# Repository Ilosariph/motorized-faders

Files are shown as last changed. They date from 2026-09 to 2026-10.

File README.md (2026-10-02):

# Motorized Fader Controller

RP2040 board (Pico-clone with RTL8720DN WiFi — GP4/GP5 not exposed) + TB6612FNG
motor drivers + Alps motorized faders.

**Two builds exist:**

| | 2-fader breadboard | 4-fader PCB |
|---|---|---|
| Faders | 2x RS60N11M9 (60 mm, 5 kΩ) | 4x RSA0N11M9 (100 mm, 10 kΩ) |
| ADC | RP2040 internal (GP26/27) | MCP3208, 12-bit SPI |
| Drivers | 1x TB6612FNG breakout | 2x TB6612FNG |
| Displays | none | 4x SSD1306 128x64 SPI |
| Buttons | none | 4 per-fader + 2 general, ADC ladder |
| Motor rail | 10 V bench supply | 9 V USB-C PD trigger |
| Docs | this file | [pcb_design.md](docs/pcb_design.md), [firmware.md](docs/firmware.md) |

The wiring below is the **2-fader breadboard** build. For the 4-fader PCB see
[docs/pcb_design.md](docs/pcb_design.md) (hardware) and
[docs/firmware.md](docs/firmware.md) (protocol, mute, displays, buttons).

Firmware in `pico/` is the **4-fader** version. It needs the MCP3208 and will
report `RAIL:fail` without the PD rail; the 2-fader build is kept in git
history.

---

## Wiring

### Power

| From | To | Notes |
|---|----|---|
| 10V supply + | TB6612FNG VM | Motor power |
| 10V supply − | Common GND | |
| Pico 3.3V (pin 36) | TB6612FNG VCC | Logic power |
| Pico GND (any) | TB6612FNG GND | |
| Pico GND (any) | 10V supply − | Common ground — important! |

The Pico gets power from USB. The 10V supply powers the motors only. All grounds must be connected together.

---

### Fader → TB6612FNG (Motor)

| Fader terminal | Connect to |
|---|---|
| Terminal 1 (GND) | GND |
| Terminal 3 (3.3V) | Pico 3.3V |
| Terminal A | TB6612FNG AO1 (fader 1) or BO1 (fader 2) |
| Terminal B | TB6612FNG AO2 (fader 1) or BO2 (fader 2) |

If the fader moves in the wrong direction, swap A and B.

---

### Fader → Pico (Sensing)

| Fader terminal | Pico pin | Notes |
|---|---|---|
| Terminal 2 (wiper) | GP26 (fader 1) | ADC position feedback |
| Terminal 2 (wiper) | GP27 (fader 2) | ADC position feedback |

Terminal T (touch) is unused — the firmware detects move completion from the
PID state machine (deadband + settle timer), not from touch.

---

### TB6612FNG → Pico (Control)

| TB6612FNG pin | Pico pin | Notes |
|---|---|---|
| AIN1 | GP2 | Fader 1 direction |
| AIN2 | GP3 | Fader 1 direction |
| PWMA | GP6 | Fader 1 speed |
| BIN1 | GP7 | Fader 2 direction |
| BIN2 | GP8 | Fader 2 direction |
| PWMB | GP9 | Fader 2 speed |
| STBY | GP10 | Driver enable |

> **Note:** GP4 and GP5 are skipped — this board does not expose them on the header. If you have a real Raspberry Pi Pico W, you can use the standard GP2–GP8 range instead and update `pico/main.py` accordingly.

---

## One Fader Only

If you only have one fader connected, the firmware still works — fader 2 will sit at its default setpoint (50%) but won't move since nothing is connected. No code changes needed.

Just leave BIN1, BIN2, PWMB, BO1, BO2, and GP27 unconnected.

---

## PC Software

Two interfaces. The **terminal tool** is for bring-up and PID tuning; the
**extension host** is what you actually run day to day.

### Terminal tool

```bash
pip install pyserial
python host/host.py
```

Type `50 75` to set fader 1 to 50% and fader 2 to 75%. Type `50` to set fader 1 only.

If the Pico isn't detected automatically, pass the port explicitly:

```bash
python host/host.py /dev/ttyACM0      # Linux
python host/host.py COM3              # Windows
```

### Extension host

Binds faders to things on the PC. `faders/config.json` declares which
extension owns which fader:

```bash
python -m faders.run
```

With `pulse_sink`, each fader controls a PulseAudio/PipeWire sink: move the
fader to change volume, change it in pavucontrol and the fader follows, and
press the fader's button to mute. The fader's display shows that sink's label
and volume — display content comes from whichever extension owns the fader, so
it describes whatever that fader actually controls.

```json
{"fader": 0, "sink": "sink-music", "min": 0, "max": 100, "label": "Music"}
```

`label` is optional and defaults to the sink name — worth setting, since real
sink names (`alsa_output.pci-0000_00_1f.3.analog-stereo`) do not fit a 128 px
screen.

### Tests

No hardware needed — the fader is simulated and `machine`/`utime` are stubbed:

```bash
python3 tests/run_all.py
```

---

## Files

| File | Description |
|---|---|
| `pico/main.py` | MicroPython firmware — copy to Pico as `main.py` |
| `pico/lib/` | Device drivers: MCP3208, buttons, SSD1306, screen layout — **upload with `main.py`** |
| `host/host.py` | PC terminal interface (calibrated 0–100% display) |
| `host/host_raw.py` | Raw 16-bit ADC viewer for wiring diagnostics |
| `faders/` | Extension host — serial transport, button/mute dispatch, plugins |
| `faders/extensions/pulse_sink.py` | Binds a fader to a PulseAudio/PipeWire sink |
| `tests/` | Test suites — run `python3 tests/run_all.py`, no hardware required |
| `docs/upload.md` | How to flash firmware to the Pico (Thonny + mpremote) |
| `docs/pid_tuning.md` | How to tune the PID controller |
| `docs/firmware.md` | 4-fader firmware — protocol, buttons, mute, displays |
| `docs/pcb_design.md` | 4-fader PCB design — ADC choice, TB6612FNG, BOM |
| `docs/modular_design.md` | Future modular expansion plan (RP2040-Zero modules) |

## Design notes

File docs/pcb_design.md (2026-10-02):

# 4-Fader PCB — Design Notes

Hardware design for a single-board 4-fader controller: 4 motorized faders, one
button per fader, 2 general buttons, one display per fader.

This supersedes the 2-fader breadboard build in the [README](../README.md).
The modular multi-board concept lives in [modular_design.md](modular_design.md);
this document is the single-board version.

---

## Summary of Decisions

| Question | Decision |
|---|---|
| ADC | MCP3208 (12-bit, 8ch, SPI) for **all 4** faders — not internal+external mix |
| Why not ADS1115 | ~215 Hz effective per channel — too slow for the PID loop |
| Motor driver | 2× TB6612FNG — **dual footprint**: SSOP-24 land + breakout header, same nets |
| Display | SSD1306 128×64 **SPI** (I2C can't address 4 — only 0x3C/0x3D exist) |
| Buttons | Resistor ladder on 2 spare MCP3208 channels — costs 0 GPIO |
| Faders | RSA0N11M9 100 mm 10 kΩ, case-mounted, soldered wire — not on PCB |
| Pin map | Fixed: SPI0 on GP16/18/19, PWM on 4 distinct slices, GP0/1 spare |
| MCU | Keep the existing RP2040 module — bare RP2040 not needed |
| Motor power | USB-C PD trigger, **jumper-set 9 V** (PD has no 10 V PDO) |
| Rail check | Divider into spare ADC CH4 — catches silent 5 V fallback, 0 GPIO |
| Assembly | Fully hand-solderable, no hot air / reflow required |
| Build order | Socket breakouts first, prove the board, then solder SSOP — **no respin** |

---

## ADC: MCP3208

**Do not use the ADS1115**, despite it being the usual recommendation. At its
maximum 860 SPS one conversion takes ~1.3 ms, and its input mux is sequential,
giving **~215 Hz per channel across 4 channels**. The firmware averages 16
samples per read (`FaderPID._raw_adc`), so a single position read would cost
~75 ms — the ADC would become the dominant time constant of the control loop
and wreck the derivative term.

| | MCP3208 | ADS1115 |
|---|---|---|
| Interface | SPI | I2C |
| Channels | 8 | 4 |
| Rate | 100 kSPS | 860 SPS |
| 4ch x 16 averaged samples | ~0.6 ms | ~75 ms |
| Resolution | 12 bit | 16 bit nominal |
| Package | **DIP-16** available | MSOP-10 only |

12 bits over 60 mm of travel is 0.015 mm/LSB. `DEADBAND` is 0.2% = 0.12 mm, so
resolution is not the binding constraint — loop rate is. The 8 channels also
leave 4 spare inputs, 2 of which the buttons use (below).

### Ratiometric reference — do not skip this

Tie MCP3208 `VREF` to the **same 3.3 V net** that feeds fader terminal 3.

The fader is a resistive divider, so if VREF and the fader supply are the same
node, supply drift cancels out of the ratio entirely. This is the single
largest accuracy win in the design and costs nothing. `VDD` and `VREF` both to
3.3 V, 100 nF on each.

### Why all 4 faders, not internal + external

Mixing the RP2040's internal ADC (faders 1-2) with the MCP3208 (faders 3-4)
would work, but:

- **No code saving.** Hardware access is isolated to `FaderPID._raw_adc()`.
  Swapping it out is the same edit whether 2 or 4 faders use it — mixed mode
  just means maintaining two paths.
- **The paths don't match physically.** The RP2040 ADC is ~8.5-9 ENOB with
  known DNL glitches from its SAR DAC capacitors; the MCP3208 with ratiometric
  VREF has a genuinely different transfer function. Faders would calibrate and
  jitter differently while `DEADBAND` / `MIN_MOVE_PCT` are global constants.
- **GP26/27/28 are needed elsewhere** — see the GPIO budget.

### Firmware change

Inject a reader callable instead of a pin number:

```python
class FaderPID:
    def __init__(self, read_raw, motor):
        self._read = read_raw          # callable -> 0..65535
        ...
    def _raw_adc(self):
        return sum(self._read() for _ in range(16)) // 16
```

Construct with `FaderPID(read_raw=lambda: mcp.read(0) << 4, motor=...)`. The
`<< 4` scales the 12-bit result into the existing 16-bit `adc_min`/`adc_max`
convention, so `calibrate()`, `read_position()` and the entire PID body are
untouched. The `POS:` / `STATE:` protocol, `host/`, and `faders/core.py` are
all unaffected.

---

## Motor Driver: TB6612FNG, direct mount

Two chips: faders 1-2 on the first, faders 3-4 on the second.

### Pinout (SSOP-24)

Names below match the **KiCad symbol** (`TB6612FNG`), so schematic pin names and
this table agree.

| KiCad pin | Pin(s) | Connects to |
|---|---|---|
| AO1 | 1 *(+2)* | fader 1 motor + |
| AO2 | 5 *(+6)* | fader 1 motor - |
| BO1 | 11 *(+12)* | fader 2 motor + |
| BO2 | 7 *(+8)* | fader 2 motor - |
| PGND1 | 3 *(+4)* | power ground |
| PGND2 | 9 *(+10)* | power ground |
| GND | 18 | signal ground |
| VM1 / VM2 / VM3 | 24 / 13 / 14 | 9 V motor rail — one net |
| VCC | 20 | 3.3 V logic |
| STBY | 19 | GP22 (both chips) |
| AIN1 | 21 | driver A: GP2 / driver B: GP10 |
| AIN2 | 22 | driver A: GP3 / driver B: GP11 |
| PWMA | 23 | driver A: GP6 / driver B: GP12 |
| BIN1 | 17 | driver A: GP7 / driver B: GP13 |
| BIN2 | 16 | driver A: GP8 / driver B: GP14 |
| PWMB | 15 | driver A: GP9 / driver B: GP15 |

**The KiCad symbol merges the doubled pins.** The physical SSOP-24 doubles
AO1 (1,2), PGND1 (3,4), AO2 (5,6), BO2 (7,8), PGND2 (9,10) and BO1 (11,12) for
current capacity, but the symbol exposes one pin each — the second number is in
parentheses above. Nothing extra is needed in the schematic; the **footprint**
must connect both pads of each pair, and layout must carry them on wide copper.
Likewise VM1/VM2/VM3 are one net, which the symbol does show as three pins.

**Check the footprint, not the symbol.** If the KiCad footprint assigns pads 2,
4, 6, 8, 10 and 12 to the same nets as their partners, this is handled. If it
leaves them unassigned, the doubled pads will not be connected — halving the
current path on the motor outputs and grounds.

### External components, per chip

| Part | Value | Placement |
|---|---|---|
| Bulk cap | 100 uF electrolytic, >=25 V | across VM/PGND, near pins 24 + 13/14 |
| VM ceramic | 100 nF X7R | same nets, right at the pins |
| VCC ceramic | 100 nF X7R | pin 20 -> pin 18, as close as possible |
| STBY pull-up | 10 kΩ | pin 19 -> 3.3 V |

**The STBY pull-up matters even though firmware drives the pin.**
`MotorDriver.__init__` sets STBY as an output, but the resistor defines the pin
state during MCU reset and before `main.py` runs. Without it STBY floats at
boot while the 10 V rail is already up, leaving the H-bridge in an undefined
state. Both chips' STBY can share one GPIO.

### Why AIN1/AIN2 and BIN1/BIN2 must come from the MCU

These are **inputs to** the TB6612FNG, not outputs from it. The chip has no
logic of its own; the motor terminals are AO1/AO2 and BO1/BO2. Per channel:

| AIN1 | AIN2 | PWM | Result |
|---|---|-----|---|
| H | L | PWM | forward |
| L | H | PWM | reverse |
| L | L | H | coast (free-spin) |
| H | H | X | brake (motor shorted) |

AIN1/AIN2 select direction, PWMA sets speed — exactly what `MotorDriver.drive()`
does from the sign and magnitude of `power`.

**Rejected optimisation:** since the firmware never uses brake, AIN2 is always
the inverse of AIN1, so a 74HC04 hex inverter could derive it and save 4 GPIO.
This does not work — with a hard inverter AIN1/AIN2 can never both be LOW, so
**coast is lost**, and `MotorDriver.stop()` coasts on every settle. Keep both
pins as GPIO.

### Layout

- VM/PGND carries the motor current: tight loop, traces >=1 mm for 1.6 A,
  bulk cap inside the loop.
- Keep PGND1/PGND2 separate from signal GND across the board; join at a single
  point at the bulk cap ground terminal.
- SSOP-24 has no thermal pad — heat leaves through the PGND pins. Pour copper.

---

## Displays: SSD1306 SPI

`modular_design.md` specified I2C SSD1306 at 0x3C / 0x3D. **That does not scale
to 4 displays** — those are the only two addresses the SSD1306 supports.

**Use the SPI variant.** Share SCK / MOSI / DC / RES across all four, give each
its own CS. Costs 4 GPIO, adds no IC, and is much faster than I2C — which
matters because redraws happen while motors are running.

Alternative, only if I2C modules are already on hand: a TCA9548A I2C mux
(addr 0x70) — 1 extra IC, 2 GPIO total, but every draw needs a channel-select
write first on the slower bus.

**Identifying which variant a module is:** count the pins.
4 pins (GND/VCC/SCL/SDA) = I2C. 7 pins (GND/VCC/D0/D1/RES/DC/CS) = SPI.

### Actual module: Adafruit 938 (1.3in, 8-pin)

The displays in hand are **Adafruit 938** — 1.3in 128x64, SSD1306, with an
onboard 3.3 V regulator and level shifters. Larger than the 0.96in this
document originally assumed, which suits a 100 mm fader better.

**8 pins, but only 7 are wired.** The extra pin is `3Vo`, an *output* from the
module's regulator for powering external parts — leave it unconnected.

| Module pin | Connects to |
|---|---|
| Data | GP19 (SPI0 MOSI) |
| Clk | GP18 (SPI0 SCK) |
| A0 | GP20 (DISP_DC) — `A0` is this board's label for DC |
| Rst | `DISP_RES` — shared RC net, see [RC reset](#free-a-gpio-rc-reset-on-display-res) |
| CS | GP21 / GP26 / GP27 / GP28 |
| **3Vo** | **no connect** |
| VIN | 5 V (see below) |
| GND | GND |

**Ships in I2C mode — cut two jumpers per board to enable SPI.** Adafruit:
*"the default interface is now I2C, not SPI"*. Do all four before assembly
rather than debugging a silent display later.

**Power VIN from 5 V (Pico VBUS), not 3.3 V.** Each module draws ~40 mA, so
four is ~160 mA — over half the Pico's 300 mA 3.3 V regulator budget, which
also feeds the faders and both TB6612FNG VCC pins. The module regulates its own
3.3 V from VIN and its level shifters handle the 5 V/3.3 V boundary, so feeding
VIN from VBUS offloads the Pico regulator entirely. This is what the onboard
regulator is for.

### PCB footprint: fit the 8-pin header

Displays are panel-mounted in the case and wired back with jumpers, so the
module never sits on the PCB. Fit an **8-pin header footprint** matching the
Adafruit 938 pinout, with the `3Vo` position present but no-connect.

Label the pads on silkscreen in module order
(`Data Clk A0 Rst CS 3Vo VIN GND`) — that is what gets read with jumpers in
hand, so matching the module's own labels beats using generic SPI names.

An 8-pin footprint still accepts a generic 7-pin SPI module or a 4-pin I2C one;
only the pad count changes, not the signals.

**Flying-lead caution:** SPI over long leads is more fragile than I2C — faster
clock, no acknowledgement. Keep display leads under ~15 cm. If glitches appear,
drop the bus to ~500 kHz before suspecting anything else.

---

## Buttons: resistor ladder on spare ADC channels

6 buttons on 2 spare MCP3208 channels, split **2 general + 4 per-fader**.
Costs **zero GPIO**.

Grouping by function rather than 3+3 keeps the mapping obvious when reading the
firmware or probing the board, and gives the 2-button channel wider margins.

```
Channel 6 -- 2 general buttons
3.3V --[10k]--+--------------------> CH6
              +--[SW_G1]--[GND]          pressed: 0.00 V
              +--[SW_G2]--[4.7k]--[GND]  pressed: 1.06 V
                                         idle:    3.30 V

Channel 7 -- 4 per-fader buttons
3.3V --[10k]--+--------------------> CH7
              +--[SW_F1]--[GND]          pressed: 0.00 V
              +--[SW_F2]--[2.2k]--[GND]  pressed: 0.60 V
              +--[SW_F3]--[4.7k]--[GND]  pressed: 1.06 V
              +--[SW_F4]--[10k]---[GND]  pressed: 1.65 V
                                         idle:    3.30 V
```

Bands are 600 mV or wider — trivially discriminated at 12 bits (1 LSB =
0.8 mV). Add 100 nF to GND at each node for debounce. Buttons are slow, so
ADC-rate polling is ample.

Simultaneous presses on one channel read as the lowest-value button. The 2+4
split means the two general buttons can never mask each other's neighbours,
which is the case most likely to be pressed together.

---

## GPIO Budget

Board exposes GP0-3, GP6-22, GP26-28 = **24 usable** (GP4/GP5 not broken out).
GP26-28 are free now that faders read via the MCP3208.

| Function | Pins |
|---|---|
| Motor control, 2x TB6612FNG (AIN1/2, PWMA, BIN1/2, PWMB) | 12 |
| STBY (shared between both chips) | 1 |
| SPI bus, shared (SCK, MOSI, MISO) | 3 |
| MCP3208 CS | 1 |
| Display DC (shared across all 4) | 1 |
| Display CS x 4 | 4 |
| **Total** | **22** |

Two pins spare. Display **RES needs no GPIO** — it is an RC power-on reset; see
[Free a GPIO](#free-a-gpio-rc-reset-on-display-res). The VM rail check also
costs no GPIO: it is a divider into spare MCP3208 channel CH4.

**The SPI bus is shared** between the MCP3208 and the four displays. This is
what makes the budget close — a separate ADC bus would need 2 more pins and put
the total at 25, over budget. It is safe because the displays are write-only
(no MISO) so only the MCP3208 ever drives MISO; devices are selected by CS.

Run the bus at ~1 MHz (safe for the MCP3208 at 3.3 V; the SSD1306 tolerates it
easily). A full 128x64 frame is 1 KB, ~8 ms per redraw — redraw on change only,
never every loop, and PID timing is unaffected.

**Touch sense is not in this budget.** The T terminal is unused; move
completion comes from the PID state machine (deadband + settle timer).

### Pin assignment is constrained, not free

The count fits, but *which* physical pin carries which signal is not arbitrary.

**SPI must land on hardware-SPI pins.** The RP2040 mapping is fixed silicon,
not a routing matrix (GP4/GP5 omitted — not broken out on this board):

| | SPI0 | SPI1 |
|---|---|---|
| SCK | GP2, GP6, GP18 | GP10, GP14 |
| MOSI (TX) | GP3, GP7, GP19 | GP11, GP15 |
| MISO (RX) | GP0, GP16 | GP8, GP12 |

The 2-fader prototype puts motor control on **GP2/GP3/GP6**, which collides
with SPI0's only usable SCK/MOSI options. Motor control must move off those
pins. Cleanest fix: run the bus on **SPI0 at GP18 (SCK) / GP19 (MOSI) /
GP16 (MISO)**, inside the otherwise lightly used GP16-22 block.

CS lines are ordinary GPIO — not fixed — so they go wherever is left.

**PWM outputs want separate slices.** GPn maps to PWM slice `(n >> 1) & 7`, and
two outputs on the same slice share a frequency. The 4 PWM pins (PWMA/PWMB on
each driver) should land on 4 different slices. Eight slices exist, so this is
easy — but it constrains the map rather than being discovered after layout.

---

## Pin Map

Validated against both hardware constraints: SPI0 on legal pins, and the four
PWM outputs on four distinct slices.

| GPIO | Signal | Notes |
|---|---|---|
| GP2 | A_AIN1 | driver A, fader 1 direction |
| GP3 | A_AIN2 | driver A, fader 1 direction |
| GP6 | A_PWMA | fader 1 speed — PWM slice 3 |
| GP7 | A_BIN1 | driver A, fader 2 direction |
| GP8 | A_BIN2 | driver A, fader 2 direction |
| GP9 | A_PWMB | fader 2 speed — PWM slice 4 |
| GP10 | B_AIN1 | driver B, fader 3 direction |
| GP11 | B_AIN2 | driver B, fader 3 direction |
| GP12 | B_PWMA | fader 3 speed — PWM slice 6 |
| GP13 | B_BIN1 | driver B, fader 4 direction |
| GP14 | B_BIN2 | driver B, fader 4 direction |
| GP15 | B_PWMB | fader 4 speed — PWM slice 7 |
| GP16 | SPI0 MISO | from MCP3208 only |
| GP17 | MCP3208 CS | |
| GP18 | SPI0 SCK | shared: ADC + 4 displays |
| GP19 | SPI0 MOSI | shared: ADC + 4 displays |
| GP20 | DISP_DC | shared across all 4 displays |
| GP21 | DISP_CS1 | |
| GP22 | STBY | both drivers |
| GP26 | DISP_CS2 | |
| GP27 | DISP_CS3 | |
| GP28 | DISP_CS4 | |

**22 assigned. GP0 and GP1 free** — reserved for I2C (SDA/SCL) if a mux or the
HUSB238 status read is ever added. GP4/GP5 are not broken out on this board.

### Why these pins

**SPI0 is forced.** The RP2040's SPI mapping is fixed silicon. Of SPI0's
options — SCK on GP2/6/18, MOSI on GP3/7/19, MISO on GP0/16 — only the GP18/19
pair leaves the low pins free for motor control. MISO takes GP16 so GP0/GP1
stay open for I2C.

**PWM slices are distinct.** Slice = `(n >> 1) & 7`; two outputs on one slice
share a frequency. GP6/9/12/15 land on slices 3/4/6/7.

**GP26-28 carry display CS, not analog.** They are the only ADC-capable pins,
but all four faders read through the MCP3208, so their analog function is
unused. CS is plain GPIO and fits there fine.

### SPI net naming — three names per net

Each device labels the same two signals differently. **Name the nets, not the
pins**, and let each symbol attach to the net:

| Net | Pico | MCP3208 (PDIP-16) | Adafruit 938 |
|-----|---|---|---|
| `SPI_SCK` | GP18 | **CLK** (pin 13) | **Clk** |
| `SPI_MOSI` | GP19 | **DIN** (pin 11) | **Data** |
| `SPI_MISO` | GP16 | **DOUT** (pin 12) | — (write-only) |
| `MCP_CS` | GP17 | **CS/SHDN** (pin 10) | — |
| `DISP_DC` | GP20 | — | **A0** |

MCP3208 DIN/DOUT are named from the *chip's* perspective: DIN is an input, so
it receives the Pico's MOSI; DOUT drives the Pico's MISO. The display has no
MISO at all, which is why sharing the bus with the ADC is safe — only the
MCP3208 ever drives that line.

**The failure to avoid:** DIN and DOUT swapped on the MCP3208 damages nothing
and gives no hardware symptom — the ADC simply reads garbage, presenting as
"the ADC does not work" with nothing pointing at the wiring. Matching pin
*labels* between parts is how that happens; matching net names is how it does
not.

### MCP3208 full pinout (PDIP-16)

| Pin | Name | Connects to |
|-----|---|---|
| 1-8 | CH0-CH7 | see *Not on the MCU* below |
| 9 | DGND | GND |
| 10 | CS/SHDN | GP17 |
| 11 | DIN | GP19 (`SPI_MOSI`) |
| 12 | DOUT | GP16 (`SPI_MISO`) |
| 13 | CLK | GP18 (`SPI_SCK`) |
| 14 | AGND | GND |
| 15 | VREF | 3.3 V — **same net as fader terminal 3** (ratiometric) |
| 16 | VDD | 3.3 V |

Tie AGND and DGND together at the ADC, and keep VREF on the same net that feeds
the faders — see [Ratiometric reference](#ratiometric-reference--do-not-skip-this).

### Not on the MCU

| Signal | Where |
|---|---|
| Fader wipers x4 | MCP3208 CH0-CH3 |
| General buttons (2) | MCP3208 CH6 ladder |
| Per-fader buttons (4) | MCP3208 CH7 ladder |
| VM rail check | MCP3208 CH4 divider |
| MCP3208 CH5 | spare |
| Display RES | `DISP_RES` — shared RC power-on reset, no GPIO |

---

## Mechanical

### Faders — RSA0N11M9, 100 mm travel

**Note the part change:** the prototype used RS60N11M9 (60 mm, 5 kΩ). The
current faders are **RSA0N11M9: 100 mm travel, 10 kΩ**, roughly 130 mm overall.
Motor spec is unchanged — 10 V DC rated, 800 mA max — so nothing in the driver
or power design moves.

The 10 kΩ element halves wiper current versus 5 kΩ, which slightly *improves*
the ratiometric ADC path. Source impedance rises, but 10 kΩ against the
MCP3208's sample-and-hold is still fine at the rates used here.

Alps lists RSA0N11M9 as **"Not Recommended for New Designs"** — it remains in
production for existing designs, but buy spares rather than assuming future
availability.

**Mounting:** M3 screws, 4 mm, into the 3D-printed case — already proven in the
prototype. Faders are **not board-mounted**: they mount to the case and connect
by soldered wire, so the PCB carries no fader mechanical load and its outline is
not driven by fader pitch.

### Wiring — 2.54 mm headers, not soldered wire

Everything off-board connects through 2.54 mm pin headers with crimp housings,
not soldered wire. **Five conductors per fader, 20 total:**

| Net | To | Notes |
|-----|----|---|
| Wiper | MCP3208 CHn via 10 kΩ RC filter | keep away from motor leads |
| 3.3 V | fader terminal 3 | same net as MCP3208 VREF — ratiometric |
| GND | fader terminal 1 | |
| Motor + | TB6612FNG AO1 / BO1 | |
| Motor - | TB6612FNG AO2 / BO2 | |

Split per fader across two headers, placed adjacent so one bundle location
serves each fader:

| Header | Pins | Carries |
|---|---|---|
| `J_Fn_MOT` | 1x02 | motor pair |
| `J_Fn_GEN` | 1x03 | wiper, 3.3 V, GND |

**No strain-relief holes needed.** They existed to protect solder joints from
flex; a header/socket pair moves the mechanical interface off the joint
entirely — the connector body takes the strain and the board side is
unplugging, not repair.

Displays use 1x08, buttons 1x02, the PD board 1x04. Label pin 1 on silkscreen
for every header.

**Polarization:** plain 2.54 mm headers are not keyed, so a 3-pin fader plug can
go on backwards, putting 3.3 V where GND belongs. The differing pin counts
(2 / 3 / 4 / 8) at least prevent cross-type mistakes. JST-XH footprints solve it
properly if the swap is made before routing — worth considering given repeated
plugging during PID tuning.

**Keep wiper and motor wires in separate bundles.** The motor pair carries
switched current at 20 kHz; the wiper is a high-impedance analog line. Coupling
happens over *bundled length*, not at the connector — so headers a few mm apart
on the board are fine, but running both in one 20 cm harness is not. Twist each
motor pair.

Button wiring is slow and low-impedance, so it can share a bundle with
anything.

### Test points

Through-hole pads or 1 mm loops, labelled:

| Test point | Why |
|---|-----|
| VM | confirm 9 V (or 10 V on the bench) before enabling motors |
| 3.3 V | regulator sanity |
| GND | x2, spread apart — scope ground for probing |
| Wiper 1 | scope the analog path, verify RC filter effect |
| SPI SCK | confirm the bus is clocking |

Free on a PCB and the difference between diagnosing by measurement and by
guesswork.

### Board outline

Not yet fixed. Since faders are case-mounted, the PCB outline is free — driven
by component area and wherever the case has room, not by fader pitch. Include
**M3 mounting holes** (3.2 mm drill) at the corners, and a keepout past the
RP2040 module's header end for its USB connector.

---

## Bill of Materials

### ICs

| Part | Qty | Package | Note |
|---|-----|---|---|
| TB6612FNG | 2 | SSOP-24 | 1 per 2 faders |
| MCP3208-CI/P | 1 | **DIP-16** | order the `/P`, not the `/SL` SOIC |
| RP2040 module (existing) | 1 | headers | GP4/GP5 not exposed |
| Female header, 20-pos, 2.54 mm | 2 | THT | RP2040 module |
| Female header, 8-pos, 2.54 mm | 4 | THT | driver breakouts, 2 per TB6612FNG |
| Adafruit 938 OLED 1.3in SSD1306 | 4 | 8-pin module | one per fader; cut jumpers for SPI |

### Passives — 0805 throughout

0805 rather than 0603: easier to place and drag-solder by hand, no real
downside at this density.

| Part | Qty | Purpose |
|---|-----|---|
| 100 uF >=25 V electrolytic | 2 | VM bulk, one per TB6612FNG |
| 100 nF X7R | ~13 | VM x2, VCC x2, MCP3208 VDD + VREF, MCU, per display, RES |

No separate 3.3 V or 5 V bulk capacitor: the Pico regulates 3.3 V on-module
with its own bulk, and there is no 5 V rail on this PCB — logic power comes
from the Pico's USB. 100 nF decoupling is sufficient at these currents.
| 10 kΩ | 9 | 2x STBY pull-up, 4x ADC filter, 2x ladder top, 1x ladder |
| 4.7 kΩ | 2 | button ladder (SW_G2, SW_F3) |
| 2.2 kΩ | 1 | button ladder (SW_F2) |
| 10 kΩ | 1 | VM divider, top leg (counted in the 9 above) |
| 3.3 kΩ | 1 | VM divider, bottom leg |
| 10 kΩ + 100 nF | 1 ea | `DISP_RES` RC power-on reset, shared by all 4 displays |
| 10 nF X7R | 4 | RC filter on each wiper |
| 100 nF | 2 | button ladder debounce |

### Wiper RC filter — high value, near-free

**10 kΩ series + 10 nF to GND on each wiper**, at the ADC input. Corner is
~1.6 kHz: roughly 22 dB of attenuation at the 20 kHz `PWM_FREQ`, while staying
far above fader mechanical bandwidth.

The series resistor must stay well below the MCP3208's sample-and-hold input
requirement — 10 kΩ against the fader's own 10 kΩ wiper impedance settles fine
at the rates used here. Do not scale R up further to shrink C.

X7R rather than C0G: **100 nF C0G does not exist in 0805** (C0G tops out near
10 nF in that size), so the filter uses 10 nF C0G-grade X7R with a
correspondingly larger resistor to hit the same corner frequency.

This filters motor PWM coupling before it reaches the ADC and should visibly
reduce the jitter that the 16x averaging currently masks — possibly allowing
that averaging to be reduced, buying loop rate back.

### Power

| Part | Qty | Note |
|---|-----|---|
| USB-C PD trigger (HUSB238) | 1 | jumper-set to 9 V, feeds VM only |
| USB-C PD charger, >=45 W | 1 | must offer a 9 V PDO; 4 motors x 800 mA = 3.2 A peak |
| 10 kΩ + 3.3 kΩ | 1 ea | VM divider into MCP3208 CH4 for rail verification |

Logic power comes from the Pico's own USB-C to the PC — no buck converter,
barrel jack or fuse needed. PD boards current-limit at the source.

### Mechanical / connectors

| Part | Qty |
|---|-----|
| Alps RSA0N11M9 fader (100 mm, 10 kΩ) | 4 |
| Tactile button (per-fader) | 4 |
| Tactile button (general) | 2 |
| Display wire pads, 8-pin | 4 |
| Fader wire pads, 5 per fader | 20 nets | soldered wire, no connectors |

---

## Power

| Rail | Source | Feeds |
|---|---|---|
| 5 V logic | Pico USB-C from the PC | RP2040 module, **display VIN x4** |
| 3.3 V | Pico onboard regulator | fader wipers, TB6612FNG VCC, MCP3208, displays |
| 9 V motor | USB-C PD trigger board | TB6612FNG VM only |

3.3 V draw is negligible: TB6612FNG VCC is ~1 mA each and four faders at 3.3 V
into 10 kΩ is ~1.3 mA total, against the Pico regulator's 300 mA.

**Displays are deliberately not on the 3.3 V rail.** Four Adafruit 938 modules
draw ~160 mA, which would consume over half that budget. They have their own
regulators, so their VIN goes to 5 V (Pico VBUS) instead.

**Common ground is mandatory.** With two independent USB sources, the PD
ground and the Pico's USB ground must be tied together on the PCB. Without it
the TB6612FNG's logic inputs have no valid reference to its motor rail.

### 9 V, not 10 V — USB PD has no 10 V PDO

The Alps RSA0N11M9 motor is rated **10 V DC, 800 mA max**. USB PD fixed PDOs
are 5 / 9 / 12 / 15 / 20 V — **10 V does not exist** in the spec. 12 V would be
20% over rated on a continuously driven part; 9 V is 10% under, which is the
safe direction to miss.

Exactly 10.0 V is reachable only through **PPS** (USB PD 3.0, 20 mV steps), and
only over I2C — PPS is a different request type, not a jumper-selectable
voltage. That requires a PPS-capable charger and 2 GPIO, for a 10% torque
difference that firmware can absorb. Not worth it.

**Firmware compensation for 9 V** — both are existing tuning constants:

| Constant | 10 V | 9 V |
|---|---|-----|
| `MIN_MOVE_PCT` | 30.0 | ~35 |
| `calibrate(motor_power=)` | 60 | ~70 |

PID output clamps at +/-100% and currently floors at 30%, so there is ample
unused band. Long travels are marginally slower; short moves dominate real use.

### Trigger board: HUSB238, jumper-set to 9 V

Adafruit HUSB238 breakout (product 5807). Few pins, mountable at the case's
USB-C cutout, wired back with 2 wires. Solder the **9 V jumper** closed.

**Set the voltage by jumper even if I2C is added later.** Adafruit's docs:
*"when configuring over I2C, the jumper settings are used on startup until the
I2C commands come over."* I2C overrides the jumper, it does not replace it. So
with a jumper left at the 5 V default, VM sits at 5 V from PD plug-in until
firmware speaks — and if the board is powered before the Pico, VM steps
5 V -> 9 V while the TB6612FNG is already live. Worse, the STBY pull-up goes to
3.3 V *from the Pico*, which is absent during that window, so STBY is genuinely
undefined with a motor rail up.

Jumper-setting the target eliminates the window entirely.

### Silent fallback — and how to catch it

If the charger cannot supply the requested PDO, the HUSB238 **falls back
silently**: it walks the source PDO list high-to-low and takes the first match,
landing on 5 V. No error, no indication.

At the bench this looks like a mechanical fault — faders crawl or stall, PID
integral winds to `INTEGRAL_MAX`, output saturates, `MIN_MOVE_PCT` sits below
stall. Identical symptoms to a stiff fader or a bad motor solder joint, so the
wrong layer gets debugged.

**Catch it with a divider into a spare ADC channel** — MCP3208 CH4 is free
after the two button ladders, so this costs **zero GPIO**:

```
VM (9 V) --[10k]--+--------> MCP3208 CH4
                  |
                [3.3k]
                  |
                 GND
```

| VM | CH4 reads |
|----|---|
| 5 V (fallback) | 1.24 V |
| 9 V (expected) | 2.23 V |
| 12 V (wrong jumper) | 2.98 V |

Widely separated and all inside the 3.3 V range. Firmware reads the rail at
boot and gates on it rather than assuming:

```
boot -> read CH4
     -> VM in expected band? -> STBY high, calibrate()
     -> else                 -> STBY stays low, emit error, skip calibration
```

Same principle as the `STATE:` protocol line — gate on a reported state, never
on an assumption. This also catches a sagging rail or a marginal cable, which
an I2C status read would not: the divider measures the actual rail, whereas
I2C only reports what was negotiated.

### Why not I2C to the HUSB238

It fits, but only just, and it buys less than the divider:

| | I2C route | Divider route |
|---|---|---|
| GPIO cost | 2 | **0** |
| Spare pins after | 0 | 1 |
| Detects 5 V fallback | yes | yes |
| Measures actual VM | no | **yes** |
| Catches sagging rail / bad cable | no | **yes** |
| Extra parts | none | 2 resistors |

The 2 GPIO are only available by first freeing the display RES pin (below).
Since the voltage is jumper-set anyway, I2C's remaining role is status
readback — which the divider does more directly.

### Reverse-polarity protection — one part, worth fitting

Not needed for the PD path (USB-C cannot be reversed), but the **bench supply
used during bring-up can be**, and that is the higher-risk phase. One part:

**P-channel MOSFET in the VM high side.** Source to supply +, drain to VM, gate
to GND through a 100 kΩ resistor. Correct polarity turns it on with a few tens
of milliohms drop; reversed, it stays off and nothing downstream sees voltage.
Better than a series diode, which would burn ~0.5 V and a watt at 3.2 A.

Sizing: needs Vds >= 20 V, Id >= 5 A, low Rds(on). Plenty of choices in SOT-223
or DPAK around CHF 0.50. An alternative is a **Schottky across VM reverse-biased
plus a fuse** — cheaper still, but it protects by blowing the fuse rather than
by staying off.

At 1.5 A bench limit the risk is modest; at the 10 A the supply can deliver, a
reversed lead into the driver bulk caps and two H-bridges is destructive.
Fit the FET.

### Free a GPIO: RC reset on display RES

SSD1306 reset is a power-on pulse: low briefly at startup, high forever after.
Firmware never asserts it again, so it does not need a GPIO.

**Net name: `DISP_RES`.** One RC network on the PCB, shared by all four
displays — each module's `Rst` pin connects to this same net.

```
         3.3 V
           |
         [10k]
           |
           +-------> DISP_RES ----+---> display 1 Rst
           |                      +---> display 2 Rst
        [100nF]                   +---> display 3 Rst
           |                      +---> display 4 Rst
          GND
```

At power-up the capacitor holds the net near 0 V, then it charges through the
resistor and the net rises to 3.3 V, releasing reset.

**Timing:** tau = 10 kΩ x 100 nF = 1 ms; the net crosses a 0.7 x VDD logic HIGH
at ~1.2 ms. The SSD1306 needs the pulse low for **3 us minimum** — a ~400x
margin, so component tolerance is irrelevant here.

Firmware must **wait ~5 ms after power-up before the first display command**.
That is free in practice: calibration sweeps run first and take far longer.

**Why not tie Rst straight to 3.3 V?** It usually works, but leaves the
controller's reset state dependent on how fast the rail rises. Two passives
remove the question.

This drops the GPIO total from 23 to **22**, leaving 2 spare. One resistor and
one capacitor total, both already in the BOM.

---

## Assembly

Everything is hand-solderable. **No hot air station or reflow needed.**

| Part | Difficulty |
|---|---|
| MCP3208 DIP-16 | trivial |
| Passives 0805 | easy |
| RP2040 module, displays, buttons, connectors | easy (THT / headers) |
| TB6612FNG SSOP-24, 0.65 mm pitch | the only fine-pitch part |

**SSOP-24 technique:** drag-soldering, no hot air. Tack one corner pin, check
alignment, tack the opposite corner, then drag a well-loaded iron tip along
each side. Bridges are expected — clear with solder wick. Needs flux (a flux
pen suffices) and ideally a fine chisel tip.

Fine-pitch soldering is **deferred, not required**: the board carries both a
SSOP-24 land pattern and breakout headers at each driver position, so the first
build can use socketed breakout boards. See
[Dual Footprints](#dual-footprints--socketed-test-build).

---

## Dual Footprints — Socketed Test Build

The board carries **two footprints for every driver position, wired to the same
nets**: the SSOP-24 land pattern for the bare TB6612FNG, and a 0.1in header
pair for a SparkFun-style breakout board.

**Populate one or the other, never both.** This is standard practice and costs
only board area. It allows the whole system — firmware, PID tuning, 4 faders,
displays, buttons — to be proven with zero fine-pitch soldering, then converted
to bare ICs later without a board respin.

Do the same for the MCP3208: it is DIP-16, so fit a **socket** rather than
soldering it down. This protects a CHF 2.23 part from rework heat and allows
swapping it if an input is damaged during bring-up.

### Build order

1. **Test build** — socket the RP2040 module, plug in TB6612FNG breakouts, seat
   the MCP3208 in its DIP socket. Solder passives, buttons, connectors.
2. Bring up and tune against all 4 faders. Everything mechanical and all
   firmware work happens here.
3. **Final build** (optional) — remove the breakouts, drag-solder bare
   TB6612FNG into the SSOP-24 lands on the same board.

### Layout rules

- Every signal net reaches **both** footprints. The SSOP land and the
  corresponding header pin are the same net, so the netlist is unchanged; only
  the physical pads differ.
- Place the SSOP-24 land **inside or beside** the header outline so the
  breakout's body does not sit over the land pattern's solder mask. A breakout
  in the socket must not physically block later access to the SSOP pads.
- Keep the VM bulk capacitor on the **main PCB**, not relying on the breakout's
  own caps. Those sit on the far side of the socket contacts — the wrong side
  of the connection.
- Keep VM/PGND copper pours continuous under both footprints.

### Electrical caveat while socketed

Motor current flows through the header contacts. The Sullins PPTC parts are
rated **3 A**, comfortably above the 800 mA per motor — but socket contacts add
resistance and are a weaker path than solder.

Treat socketed operation as the **test configuration, not the final one**. It
works, but soldered SSOP with proper copper pours is the better long-term motor
path.

### Footprint measurements — taken

Both boards were measured directly rather than trusted to datasheets, since
neither is a reference design. Both came back Pico-standard:

**RP2040 module (RP2040+RTL8720 clone).** Row spacing is **identical to a stock
Pico**: 17.78 mm (7 x 0.1in) between the two 20-pin rows, so a standard KiCad
Pico footprint fits. The board runs slightly longer than the 20-pin rows with
only minor USB overhang — a small keepout past the header end is enough.

**TB6612FNG breakout.** The SparkFun board is 27 x 19 x 3 mm with pins on two
0.1in headers, inputs one side and outputs the other. Measured from the board
in hand: **8 pins per side (16 total)**, row spacing **identical to the Pico's
17.78 mm**. SparkFun's hookup guide states pin functions but not the physical
row layout, hence measuring.

Both footprints can therefore use standard 2.54 mm / 17.78 mm geometry.

---

## Future: I2C Expansion (TCA9548A / PCA9548A)

Not needed for this design — recorded because the 2 spare GPIO make it
available, and because it is the natural escape hatch if the display route
changes.

An 8-channel I2C switch lets multiple devices with **identical fixed addresses**
share one bus. Mux address is 0x70 (0x70-0x77 via A0/A1/A2), and a channel is
selected by writing a one-byte mask before each transaction.

**Where it would be used here:**

- **I2C displays instead of SPI.** SSD1306 has only two selectable addresses
  (0x3C / 0x3D), so four on one bus is impossible without a mux. Costs 2 GPIO
  total instead of 4 CS lines — a net gain of 2 pins over the SPI route.
- **Any further I2C devices** once SDA/SCL exist — an I/O expander for more
  buttons, sensors, a second fader bank.

**Sourcing note:** the usual `TCA9548APWR` is **out of stock at DigiKey until
December 2026**. The `PCA9548APWR` is the pin-compatible NXP-origin equivalent,
in stock, and DigiKey lists the two as direct substitutes. Use the PCA unless
the TCA is back.

Both are **TSSOP-24 at 0.65 mm pitch** — the same pitch as the TB6612FNG, so no
new soldering capability is needed. A breakout module is the alternative
(Bastelgarage stocks one at CHF 5.90, though it was out of stock when checked).

If the board is ever laid out with a mux in mind: it needs the two I2C nets,
100 nF decoupling, and pull-ups (4.7 kΩ to 3.3 V on SDA and SCL) — values
already in the BOM.

---

## Sourcing — DigiKey Switzerland

All part numbers verified in stock on digikey.ch. Free shipping over CHF 70;
below that, CHF 23. Ships from Germany, typically ~48 h.

No Swiss hobby shop (Bastelgarage, Pi-Shop, Play-Zone) carries the bare
MCP3208, the SSOP TB6612FNG, or an SPI SSD1306 — they stock modules, not ICs.
Distrelec (Zurich) may carry the ICs but blocks automated lookup; worth a
manual check for the three semiconductors if buying Swiss matters.

### Semiconductors

| Part | DigiKey / MPN | Qty | CHF ea |
|---|---|-----|---|
| ADC, 12-bit 8ch SPI, DIP-16 | `MCP3208-CI/P` | 2 | 2.23 |
| Motor driver, SSOP-24 | `TB6612FNG,C,8,EL` | 3 | 1.64 |

Buy one spare of each — both are the parts a wiring mistake kills.

### Capacitors

| Purpose | MPN | Qty | CHF ea | Notes |
|---|-----|-----|---|---|
| VM bulk (per driver) | `EEU-FR1E101B` | 2 | 0.38 | 100 uF 25 V, 130 mOhm ESR, 6.3x12.7 mm, 5 mm pitch |
| ~~10 V rail input bulk~~ | ~~`EEU-FR1E471`~~ | — | — | **not needed** — see below |
| Decoupling, everywhere | `CL21B104KBCNNNC` | 25 | 0.08 | 100 nF 50 V X7R 0805 |
| Wiper RC filter | `CL21B103KBANNNC` | 10 | ~0.08 | 10 nF 50 V X7R 0805 |

**The 470 uF rail-input cap was dropped.** It belonged to the original
bench-PSU-and-barrel-jack architecture, where it buffered a long DC cable from
a wall supply. With the PD trigger board mounted inches away and carrying its
own output capacitance, it is redundant — the two 100 uF at the drivers are the
ones that matter. Harmless to own, but it does not go on the board.

**Why these electrolytics:** Panasonic FR series is low-ESR and 105 C rated.
ESR is the spec that matters for a motor rail — it sets how well the cap
absorbs the current spikes when the H-bridge switches. A general-purpose 105 C
cap at ~1 ohm ESR would not do the job. Both are 5 mm lead pitch, 25 V for
headroom over the 10 V rail.

Order 100 nF in quantity — at 0.08 CHF they are consumable, and the design
uses ~12 with more wanted for rework.

### Resistors — 0805, 1%

Yageo RC0805 series, pattern `RC0805FR-07<value>L`:

| Value | MPN | Per board | Purpose |
|---|-----|---|---|
| 10 kΩ | `RC0805FR-0710KL` | 9 | 2x STBY pull-up, 4x ADC filter, 2x ladder top, 1x ladder |
| 4.7 kΩ | `RC0805FR-074K7L` | 2 | button ladder (general SW_G2, per-fader SW_F3) |
| 2.2 kΩ | `RC0805FR-072K2L` | 1 | button ladder (per-fader SW_F2) |

The 4.7 kΩ and 2.2 kΩ come from the **2 general + 4 per-fader** ladder split;
the earlier 3.3 kΩ belonged to the abandoned 3+3 grouping and is not needed.

Ladder values are not critical — the bands are 600 mV or wider against a 0.8 mV
LSB, so anything close works. Substitute from stock rather than reordering for
these two lines alone.

A 0805 resistor assortment book is often better value than reels if you do not
have one — it covers rework and future revisions.

### Tactile buttons — 3D-printed cover

**`B3F-4050`** (Omron/Aratas), 0.42 CHF, 22,666 in stock. Qty 6.

| Spec | Value |
|---|---|
| Body | 12.0 x 12.0 mm |
| Plunger height above PCB | 7.30 mm |
| Operating force | 130 gf |
| Travel | 0.30 mm |
| Life | 3,000,000 cycles |
| Mount | through-hole, 4 pin |

This is the right part for a printed cover, specifically because of the
**7.30 mm plunger**: the tall stem gives clearance for a front panel of real
thickness, so the printed cap sits on the plunger rather than needing the panel
to be paper-thin. The 12x12 mm body is also large enough to print a stable cap
for without it rocking.

**Force choice:** the near-identical `B3F-4055` is the same body and stem at
**260 gf** — twice the force. For faders you tap while mixing, 130 gf is the
better feel; 260 gf is for gloved or anti-accidental use. Do not order 4055 by
mistake, the part numbers differ by one digit.

Omron B32 series key tops fit these if a printed cap does not work out.

### Displays — still open

No cheap generic SPI SSD1306 at DigiKey. Either:

- **`1528-1447-ND`** (Adafruit 326), ~CHF 16 ea — 0.96in 128x64 SSD1306,
  I2C **or** SPI selectable by cutting a jumper on the back. 4x = ~CHF 64.
- **Generic 7-pin SPI SSD1306** from AliExpress, ~CHF 3-4 ea, 2-4 week ship.
  These are exactly the 7-pin modules this design assumes, no jumper cutting.

### Sockets and headers

| Part | MPN | Qty | CHF ea |
|---|-----|-----|---|
| Female header, 20-pos, 1 row (RP2040) | `PPTC201LFBN-RC` (S7018-ND) | 2 | 0.92 |
| Female header, 8-pos, 1 row (drivers) | `PPTC081LFBN-RC` (S7006-ND) | 4 | ~0.45 |

Sullins PPTC series: 2.54 mm pitch, through-hole, 8.51 mm insulator height,
tin-plated, 3 A rated. 16,583 in stock.

Two 20-position strips socket the RP2040 module. The SparkFun TB6612FNG
breakout has **8 pins per side (16 total)** — measured, not from the datasheet —
so each driver position takes two 8-position strips, four per board.

Buy 8-position rather than cutting down 20s: a 20 yields only two clean 8s
(one position is lost at each cut), so cutting costs more strip and wastes a
third of each. The same family covers other lengths if a revision needs them:
`PPTC061LFBN-RC` (6), `PPTC101LFBN-RC` (10) — identical pitch and height, so
everything seats at a consistent level.

**The MCP3208 does not need a socket.** DIP-16 is the easiest part on the board
to desolder if one is ever damaged, and spares are cheap. Solder it directly.
If a socket is wanted for the bring-up board anyway, DigiKey files these under
*IC Sockets*, not headers: `A 16-LC-TT` (AE9992-ND), CHF 1.01, 16-pos 2x8,
0.3in row spacing.

**Lead time:** these carry an 11-week manufacturer lead time. Irrelevant while
stock lasts, but do not leave them off an order assuming they can be added
later.

### Power

| Part | MPN / DK# | Qty | CHF ea |
|---|---|-----|---|
| USB-C PD trigger, jumper or I2C | Adafruit **5807** (1528-5807-ND) | 1 | 4.77 |
| VM divider, top leg | `RC0805FR-0710KL` | 1 | 0.014 |
| VM divider, bottom leg | `RC0805FR-073K3L` | 1 | 0.018 |

The divider uses 10 kΩ and 3.3 kΩ — **both already in the basket**, so the rail
check adds no new line item. (The 3.3 kΩ was left over from the abandoned 3+3
button ladder; this gives it a purpose.)

**In stock at DigiKey** (2,256 units), so this stays a single order.

Order **5807** specifically, not 5991 — both use the HUSB238, but 5807 is the
solder-jumper version this design needs: *"cut the 5V jumper and solder close
the 9V, 12V, 15V, 18V or 20V jumper"*. I2C remains available on the same board
if it is ever wanted.

### Panel-mounting the USB ports

Both USB-C ports (Pico and HUSB238) sit on modules inside the case, so each
needs to reach a panel cutout.

**Recommended: short USB-C extension cables**, male-to-female, 0.3-0.5 m, run
from the module to a panel cutout and secured with a printed bracket or
P-clip. Cheap, no special parts, and the printed case can hold the female end
directly.

**Feedthrough connectors exist but are poor value here.** Cliff's DUALSLIM
range (e.g. `CP30701MB3`, 4654-CP30701MB3-ND) is a proper panel-mount USB-C
receptacle-to-receptacle feedthrough with a screw flange — but it is
**CHF 16.53 each and out of stock** at DigiKey, with a 6-week lead time. Two of
them would cost more than every semiconductor in this design.

Since the case is 3D printed, a cutout sized to a cable's moulded shell plus a
printed retaining clip does the same job for nothing. If PD current matters,
check the extension is rated for it — many cheap USB-C cables are 3 A, which
covers 9 V x 3 A = 27 W comfortably.

### Future expansion — not needed now

| Part | MPN / DK# | CHF ea | Note |
|---|---|---|---|
| I2C 8-ch switch | `PCA9548APWR` (296-21775-1-ND) | 1.46 | **in stock**, 13,910 |
| I2C 8-ch switch (alt) | `TCA9548APWR` (296-34905-1-ND) | 1.19 | **out of stock** until Dec 2026 |

Pin-compatible; DigiKey lists them as direct substitutes. TSSOP-24, 0.65 mm —
same pitch as the TB6612FNG. Only needed if the design moves to I2C displays or
gains further I2C devices.

### Not from DigiKey

Cheaper at Bastelgarage or similar: pin headers, and a TCA9548A breakout module
(CHF 5.90) if a mux is ever wanted without TSSOP soldering.

**No longer needed:** the bench PSU, barrel jack, fuse holder and 10 V/5 A
supply are all replaced by the USB-C PD trigger board. A buck converter is only
required if the 12 V-plus-buck route is taken instead of jumper-set 9 V.

If breadboarding the TB6612FNG before committing to a PCB, add 2x SSOP-24 to
DIP adapter boards (~CHF 2 ea).

### Basket total

Semiconductors + passives + buttons + headers lands around CHF 28. With 4x Adafruit 326
it clears the CHF 70 free-shipping threshold; without displays it does not, so
either add the displays, stock up on passives, or accept the CHF 23 shipping.

---

## Firmware

Implemented on branch `feat/4-fader-pcb-firmware`. The deferred items from this
document are done; see [firmware.md](firmware.md) for the protocol and module
layout.

| Item | Where |
|---|---|
| MCP3208 driver | `pico/lib/mcp3208.py` |
| `FaderPID` ADC injection | `pico/main.py` — `FaderPID(read_raw=...)` |
| Button-ladder decode | `pico/lib/buttons.py` |
| VM rail check at boot | `pico/main.py` — `read_vm_rail()`, gates STBY |
| Display output | `pico/lib/ssd1306_spi.py`, `pico/lib/fader_screen.py` |
| 9 V compensation | `MIN_MOVE_PCT = 35`, `CAL_MOTOR_POWER = 70` |

**One change to the design assumptions.** `calibrate()` no longer sweeps for a
fixed number of steps. The prototype's 15x30 ms sweep was sized for the 60 mm
RS60N11M9; at 100 mm the carriage does not reach the end stop in that time, and
the result is a calibration against a mid-travel point — which then corrupts
every position report. The sweep now runs until the wiper stops changing
(`CAL_STALL_COUNTS` over `CAL_STALL_READS`), with a 4 s backstop that reports
`DBG:calibration sweep timed out` rather than hanging boot on an unplugged
motor. No hardware impact.

## Open Items

- Fix the board outline and M3 hole positions once the case layout is decided.
  Faders are case-mounted, so the PCB outline is otherwise unconstrained.
- Pick a reverse-polarity P-FET (Vds >= 20 V, Id >= 5 A, SOT-223/DPAK) if
  fitting one — not yet in the basket.
- Bring-up order for the firmware: verify `RAIL:ok` before trusting any PID
  behaviour, then check each fader calibrates to a full-span `adc_min`/`adc_max`
  before tuning. A short span means the sweep is stalling early.

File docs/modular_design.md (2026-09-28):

# Modular Fader System — Design Plan

This document describes how to evolve the single-Pico prototype into a modular, expandable system using RP2040-Zero modules and magnetic connectors.

---

## Goal

Each module contains:
- 2 motorized faders (Alps RS60N11M9)
- 2 small OLED screens (SSD1306, 128×64)
- Independent motor driver

Modules connect together magnetically and can be added or removed without tools. The Pico W acts as the master controller, bridging USB/WiFi on one side and the module UART chain on the other.

---

## Controller Choice: RP2040-Zero

The **RP2040-Zero** (Waveshare) is the same RP2040 chip as the Pico, in a compact 23×18mm form factor. It is the natural choice for modules because:

- **4 ADC channels** — covers 2 fader wipers with no external ADC IC
- **30 GPIO pins** — plenty for motor driver, I2C, UART
- **5V tolerant VIN** — onboard 3.3V regulator, powered directly from the 5V bus
- **Same MicroPython** as the Pico — the `main.py` firmware ports with pin number changes only
- **No WiFi radio** — no ADC noise, no unnecessary complexity (WiFi not needed; Pico W is the network bridge)
- **~€3–4** — cheaper than ESP32 or D1 Mini

### GPIO Assignment (RP2040-Zero)

| GPIO | Signal |
|---|---|
| GP26 / ADC0 | Fader 1 wiper |
| GP27 / ADC1 | Fader 2 wiper |
| GP2 | AIN1 (fader 1 direction) |
| GP3 | AIN2 (fader 1 direction) |
| GP4 | PWMA (fader 1 speed) |
| GP5 | BIN1 (fader 2 direction) |
| GP6 | BIN2 (fader 2 direction) |
| GP7 | PWMB (fader 2 speed) |
| GP20 | I2C0 SDA (2× SSD1306 OLED) |
| GP21 | I2C0 SCL |
| GP0 | UART0 TX (upstream toward master) |
| GP1 | UART0 RX (upstream toward master) |
| GP8 | UART1 TX (downstream toward next module) |
| GP9 | UART1 RX (downstream toward next module) |
| STBY | Tied HIGH via 10kΩ to 3.3V |

This is identical to the Pico firmware pin layout — porting is a matter of changing UART and I2C pin assignments only.

---

## Connector Choice: 5-pin magnetic, UART daisy-chain

```
Pin 1: 10V  — motor supply (VM on TB6612FNG)
Pin 2: 5V   — logic supply (RP2040-Zero VIN → onboard 3.3V LDO)
Pin 3: GND
Pin 4: TX
Pin 5: RX
```

Each module has two connectors: upstream (toward master) and downstream (toward next module). The TX/RX lines cross between connectors so that TX of one module connects to RX of the next.

**Why UART over I2C on the connector:**
- I2C has capacitance limits (~400pF) that restrict cable length between modules.
- UART works reliably at longer distances without bus repeaters.
- Full-duplex: modules can send position data without being polled.

---

## Communication Protocol

Line-based ASCII over UART (115200 baud). Each message ends with `\n`.

### Master → Module

```
MODULE:1:SET:50.0,75.0\n
```

- `1` is the module address (1-indexed).
- Each module acts if the address matches, then **forwards the packet downstream** unchanged.
- Module address set as a constant in firmware (or via a GPIO strap pin tied to GND/3.3V at boot).

### Module → Master

```
MODULE:1:POS:47.3,82.1\n
```

- Each module sends position upstream at ~20Hz.
- Intermediate modules forward packets they did not originate upstream.

### Additional commands (future)

```
MODULE:1:TUNE:0.8,0.05,0.02\n   -> live PID tuning
MODULE:*:SET:50.0,50.0\n         -> broadcast to all modules
MODULE:1:DISP:Vol\n              -> set OLED label text
```

---

## Power Bus Design

```
[10V PSU]──────────────────────────────────────── 10V rail ──► TB6612FNG VM
[10V PSU]──[buck converter 10V→5V]─────────────── 5V rail  ──► RP2040-Zero VIN

[Pico W]──5-pin connector──[Module 1]──5-pin connector──[Module 2]──► ...
```

One 10V supply powers the whole chain. A single **LM2596 or MP1584 buck module** steps it down to 5V for the logic rail — one converter for the entire chain, not per module.

**Per-module power budget (peak):**

| Component | Current (10V rail) | Current (5V rail) |
|---|---|---|
| 2× fader motor (800mA max each) | up to 1600 mA | — |
| RP2040-Zero | — | ~50 mA |
| 2× SSD1306 OLED | — | 20 mA |
| **Total peak** | **1600 mA** | **70 mA** |

Normal PID operation: motors rarely draw more than 200–300mA each. A **10V/3A supply** handles 2 modules; **10V/5A** covers 4+ modules.

The TB6612FNG is rated 1A continuous / 3A peak per channel at up to 13.5V — handles 10V and 800mA comfortably.

---

## Components Needed Per Module

| Component | Qty | Notes |
|---|-----|---|
| RP2040-Zero | 1 | Main controller |
| TB6612FNG | 1 | Dual motor driver |
| SSD1306 OLED (128×64, I2C) | 2 | One per fader |
| 100µF electrolytic cap | 1 | 10V motor rail decoupling |
| 100nF ceramic cap | 4 | Per-IC supply decoupling |
| 10kΩ resistor | 1 | STBY pull-up to 3.3V |
| 5-pin magnetic connector | 2 | Upstream + downstream |

No external ADC, no LDO — the RP2040-Zero handles everything natively.

---

## Master Role (Pico W)

```
PC ──USB serial──► Pico W ──UART──► Module 1 ──UART──► Module 2 ──► ...
     (SET/POS protocol)            (MODULE:N: protocol)
```

The Pico W translates the existing `SET:f1,f2\n` / `POS:f1,f2\n` PC protocol into the `MODULE:N:SET/POS` chain protocol. `host.py` needs only minor changes to address multiple modules by index.

The Pico W's second UART (GP4/GP5 on a genuine Pico W; remap to e.g. GP8/GP9 on the current RP2040+RTL8720 board, which doesn't expose GP4/GP5) drives the module chain; its USB serial continues talking to the PC.

Optionally, the Pico W can expose a WiFi TCP server instead of USB, removing the cable entirely.

---

## Physical Design Notes

- **PCB size**: RP2040-Zero (23×18mm) is compact enough for a module PCB alongside two faders (~60mm travel each) and two small OLEDs.
- **Connector placement**: one 5-pin magnetic connector at each end of the PCB. TX/RX cross on the PCB traces so the connector pinout is symmetric (same physical connector on both ends).
- **OLED placement**: one SSD1306 above each fader, showing current position and target.
- **I2C addresses**: SSD1306 #1 = 0x3C (ADDR→GND), SSD1306 #2 = 0x3D (ADDR→VCC). Both on the same I2C bus.

---

## Development Sequence

1. **Port `pico/main.py` to RP2040-Zero** — change UART/I2C pin numbers, remove WiFi disable call. The PID logic is identical.
2. **Test single module** with one fader, verify ADC and PID work.
3. **Add OLED output** — display position and setpoint on each SSD1306.
4. **Add UART passthrough** — module relays unknown packets downstream/upstream.
5. **Test 2-module chain** with Pico W as master.
6. **Design PCB** in KiCad — RP2040-Zero footprint, TB6612FNG, 2× SSD1306 headers, 5-pin connector footprints at each end.
7. **Order and test** before scaling to more modules.

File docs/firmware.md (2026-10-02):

# Firmware — 4-Fader Build

Implements the deferred firmware items from [pcb_design.md](pcb_design.md):
MCP3208 ADC, four SSD1306 SPI displays, the button ladders, the VM rail check,
and mute.

---

## Module Layout

| File | Role |
|---|---|
| `pico/main.py` | Pin map, PID, state machine, protocol, main loop |
| `pico/lib/mcp3208.py` | 12-bit 8-channel SPI ADC |
| `pico/lib/buttons.py` | Resistor-ladder decode, debounce, press edges |
| `pico/lib/ssd1306_spi.py` | SSD1306 SPI driver + 5x7 font |
| `pico/lib/fader_screen.py` | Per-fader screen layout |

Upload `pico/main.py` **and** the `pico/lib/` directory — see
[upload.md](upload.md).

`FaderPID` takes a `read_raw` callable rather than a pin number, so all
hardware access sits behind one injection point. The PID body, `calibrate()`
and `read_position()` are unchanged from the 2-fader prototype.

---

## Serial Protocol

115200 baud over USB, line-based ASCII. Additive — a host that does not know a
prefix ignores it.

### Pico to host

| Line | Meaning |
|---|---|
| `POS:f1,f2,f3,f4` | Position, 0-100%. 20 Hz while engaged, on-change while idle |
| `RAW:r1,r2,r3,r4` | Raw ADC 0-65535, sent only while engaged, diagnostics |
| `STATE:idx,IDLE\|MOVING\|SETTLING` | State edge, `idx` 1-based |
| `BTN:F1..F4\|G1\|G2` | Button press edge |
| `MUTE:idx,0\|1` | Mute state confirmation |
| `RAIL:ok,<volts>` / `RAIL:fail,<volts>` | VM check at boot |
| `CAL:start` / `CAL:done` | Calibration phase |
| `DBG:<text>` | Diagnostics |

### Host to Pico

| Line | Meaning |
|---|---|
| `SET:f1,f2,f3,f4` | Setpoints. An **empty slot leaves that fader alone** |
| `MUTE:idx,0\|1` | Mute/unmute fader `idx` (1-based) |
| `DISP:idx,line1,line2` | Display text for fader `idx` (1-based) |

Only these three prefixes are parsed as input. Everything else on stdin is
discarded, which matters because the Pico's own output can arrive back as a USB
CDC loopback.

`DISP:` splits on the first two commas only, so `line2` may contain commas.
The host strips commas and newlines anyway (`faders/core.py::_sanitize`).

---

## Buttons: firmware reports, host decides

The firmware assigns buttons **no meaning**. It decodes which button was
pressed and emits `BTN:`; `FaderHost._handle_button` maps that to an action.

This is deliberate. The planned layer-switch button — one general button
re-purposing the four fader buttons — becomes a change to that one method, with
no firmware, protocol, or PCB change. Currently:

| Button | Action |
|---|---|
| `F1`-`F4` | Toggle mute on the matching fader |
| `G1`, `G2` | No function. Reported to extensions via `on_button` |

Presses are edge-triggered: a held button reports once. Release is not
reported — nothing needs it.

### Ladder decode

Thresholds are derived from the resistor values, not hardcoded ADC counts, so
the BOM and the firmware cannot drift apart:

```
CH6: G1 = 0R, G2 = 4k7                        -> 0.00 V, 1.06 V
CH7: F1 = 0R, F2 = 2k2, F3 = 4k7, F4 = 10k    -> 0.00, 0.60, 1.06, 1.65 V
```

Each band's boundary is the midpoint to its neighbour, leaving ≥±3% of
full-scale margin — far more than resistor tolerance needs. A press must read
the same band twice running (`DEBOUNCE_SAMPLES`) to count, on top of the 100 nF
at each node.

---

## Mute

Pressing a fader button parks that fader at the bottom and remembers where it
was. Pressing again drives it back.

The split follows the same principle as the buttons:

- **Firmware owns the motion** — park, remember, restore. No host round trip
  for the mechanical behaviour.
- **Host owns the meaning** — which button mutes what, and applying mute to
  whatever the fader controls (a PulseAudio sink).

Sequence:

```
button press -> BTN:F3
             -> host: toggle_mute(2) -> MUTE:3,1
             -> firmware: save position, engage 0.0
             -> MUTE:3,1 (confirmation)
             -> host: pactl set-sink-mute sink-chat 1
```

The host tracks mute from the **confirmation**, never from the command it
sent — the same gate-on-reported-state rule the `STATE:` line exists for.

### Moving a muted fader by hand

Specified behaviour: drag a muted fader somewhere, press mute again, and it
re-mutes from the new position.

`FaderPID.update()` therefore tracks manual movement while muted and IDLE, and
treats the new position as the restore target.

**The park zone matters.** Muting leaves the fader sitting at the bottom, which
is itself "movement while muted". Without a guard, the parked position
immediately overwrites the position being restored — so pressing mute twice
loses it. Positions below `MUTE_PARK_ZONE_PCT` (3%) are therefore not read as
a new target. 3% clears the 1% calibration margin at each end with room to
spare, and a fader a user genuinely parks that low is already at the bottom.

`tests/test_firmware.py` covers three full mute cycles and a deliberate 12%
target against this.

---

## Displays

Content is **host-supplied**, so the screen describes whatever plugin owns the
fader. `pulse_sink` pushes the sink label and volume; another extension on the
same fader would label it differently with no firmware change.

```
+------------------------------+
| Music                        |  line1, scale 2 (scale 1 if too long)
| vol 78%                      |  line2
|                              |
| [####################----]   |  position bar, firmware-owned
|                      78.2%   |  live position, firmware-owned
+------------------------------+
```

Muted replaces the readout with a solid full-width bar along the bottom, label
knocked out of it. The SSD1306 is **monochrome** — there is no colour to use,
so mute reads as a large filled block, which carries across a desk where four
small letters do not.

**Redraw discipline.** A full 128x64 frame is 1 KB, ~8 ms at 1 MHz. Screens
redraw only when their content actually changes (`FaderScreen.draw()` returns
`False` otherwise), position changes are quantised to 0.5%, and the main loop
draws **at most one display per pass** so four simultaneous redraws cannot
stall the PID loop for ~32 ms at once.

A display that fails to initialise is logged and set to `None`; the faders keep
working without it.

---

## VM Rail Check

The HUSB238 falls back to 5 V silently if the charger cannot supply 9 V. At the
bench that looks exactly like a stiff fader or a bad motor joint, so the
firmware measures the rail instead of assuming it:

```
boot -> STBY low (motors disabled)
     -> read CH4 divider
     -> 9 V +/- 1.2 V ? -> STBY high, calibrate()
     -> else            -> STBY stays low, RAIL:fail, skip calibration
```

On failure the displays show `RAIL FAIL` and the measured voltage, and the host
prints a warning naming the 9 V jumper. Buttons and screens still work, so the
fault is visible rather than silent.

| VM | CH4 | Verdict |
|----|-----|---|
| 5 V | 1.24 V | fail — PD fell back |
| 9 V | 2.23 V | ok |
| 12 V | 2.98 V | fail — wrong jumper |

---

## Calibration

Sweeps run **until the wiper stops moving**, not for a fixed duration.

The prototype swept 15 steps of 30 ms, sized for 60 mm of travel. The
RSA0N11M9 has 100 mm; that sweep does not reach the end stop, and calibrating
against a mid-travel point corrupts every subsequent position report. The
sweep now ends when consecutive reads differ by less than `CAL_STALL_COUNTS`
for `CAL_STALL_READS` in a row — the carriage is against the stop.

`CAL_SWEEP_TIMEOUT_MS` (4 s) is a backstop only: an unplugged or jammed motor
emits `DBG:calibration sweep timed out` instead of hanging boot.

Wiper polarity is still detected rather than assumed.

---

## Tests

No hardware required — `machine` and `utime` are stubbed and the fader is
simulated as a plant that integrates motor drive over time.

```bash
python3 tests/run_all.py
```

| Suite | Covers |
|---|---|
| `tests/test_firmware.py` | MCP3208 framing, calibration at both polarities, PID, pin map, mute cycling, protocol parsing, ladder decode, rail check, redraw gating |
| `tests/test_host.py` | POS/BTN/MUTE/RAIL parsing, button dispatch, loopback guard, display de-dup, `pulse_sink` pactl calls |
| `tests/test_integration.py` | Firmware + host over a loopback pipe: real button press to real fader travel |

The integration suite is the one that matters for the mute behaviour — it
presses a simulated button through the resistor ladder and asserts the
simulated fader reaches the bottom and comes back.

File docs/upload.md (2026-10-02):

# Uploading firmware to the Pico

The Pico runs MicroPython. `pico/main.py` must be copied to the device as
`main.py` so it runs on boot.

**The `pico/lib/` directory must be uploaded too.** `main.py` imports the
MCP3208, button-ladder and display drivers from it. A missing or stale `lib/`
fails at boot with an `ImportError`, not with a missing feature — so upload
both, every time.

## Thonny (GUI, recommended for quick edits)

1. Plug the Pico into USB.
2. Open Thonny.
3. Bottom-right status bar → click the interpreter name → choose
   **MicroPython (Raspberry Pi Pico)**. Pick the serial port if asked
   (e.g. `/dev/ttyACM0`).
4. **View → Files** to show two panes: *This computer* (top) and
   *Raspberry Pi Pico* (bottom).
5. In the top pane, navigate to this repo's `pico/` directory.
6. Right-click `main.py` → **Upload to /**. The file appears in the
   bottom pane as `main.py`.
7. Right-click the `lib` folder → **Upload to /**. It appears in the
   bottom pane as `lib`, containing four `.py` files.
8. Hit the red **Stop** button (or `Ctrl+F2`) to soft-reset — firmware
   starts. Output appears in the Shell pane.

Editing in place: double-click `main.py` in the bottom pane, edit, save
(`Ctrl+S`) — Thonny writes back to the Pico. Stop/restart to apply.

Close Thonny (or disconnect) before running `host/host.py` or
`host/host_raw.py` — only one program can hold the serial port.

## pico/upload.sh (CLI, fastest for repeated uploads)

Inside the nix shell (provides `mpremote`):

```
./pico/upload.sh        # upload main.py + lib/, reset
./pico/upload.sh -r     # same, then attach the REPL
```

Picks the first `/dev/ttyACM*` automatically; override with
`PORT=/dev/ttyACM1 ./pico/upload.sh`. Stop `host.py` / `host_raw.py` /
Thonny first — only one program can hold the serial port.

Raw equivalent, if you want the steps by hand:

```
mpremote fs mkdir :lib
mpremote fs cp pico/lib/mcp3208.py :lib/mcp3208.py
mpremote fs cp pico/lib/buttons.py :lib/buttons.py
mpremote fs cp pico/lib/ssd1306_spi.py :lib/ssd1306_spi.py
mpremote fs cp pico/lib/fader_screen.py :lib/fader_screen.py
mpremote cp pico/main.py :main.py
mpremote reset
```

Watch serial output:

```
mpremote
```

Exit with `Ctrl+]`.

## First-time MicroPython install

If the Pico is brand new or has been used for C/Arduino:

1. Hold the **BOOTSEL** button while plugging in USB. Pico mounts as a
   USB drive named `RPI-RP2`.
2. Download the latest Pico W MicroPython UF2 from
   https://micropython.org/download/RPI_PICO_W/
3. Drag the `.uf2` onto the `RPI-RP2` drive. The Pico reboots into
   MicroPython.
4. Then upload `main.py` using either method above.

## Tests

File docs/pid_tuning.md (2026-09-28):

# PID Tuning Guide — Motorized Faders

This guide explains how to tune the PID controller in `pico/main.py` for the Alps RS60N11M9 motorized fader.

---

## What the Constants Do

All tuning constants live at the top of `main.py`. You do not need to reflash — edit the values and save to the Pico.

### Kp — Proportional Gain

The motor power is directly proportional to the distance from the target:

```
motor_power = Kp × (target - current_position)
```

- **Too low**: Fader moves sluggishly, barely reaches the target.
- **Too high**: Fader oscillates back and forth around the target.
- **Just right**: Fader moves briskly and settles with little or no overshoot.

Start here. Kp is the most important constant.

### Ki — Integral Gain

Accumulates error over time, correcting a fader that consistently stops short of the target:

```
integral_term = Ki × (sum of error × time)
```

- **Too low**: Fader stops a percent or two short of the target and stays there.
- **Too high**: Fader oscillates slowly, with a growing wobble that doesn't damp out.
- **Just right**: Fader reaches exactly the target position after settling.

Only add Ki *after* Kp and Kd are set. Most faders don't need much — start at 0.01.

### Kd — Derivative Gain

Reacts to how fast the error is changing, damping the motor as the fader approaches target:

```
derivative_term = Kd × (error_change / time_elapsed)
```

- **Too low**: Fader overshoots and takes several oscillations to settle.
- **Too high**: Fader vibrates rapidly (reacting to ADC noise), feels jittery.
- **Just right**: Fader glides smoothly into position with minimal overshoot.

Note: Kd is sensitive to ADC noise. If you increase it and see vibration at rest, reduce it.

---

## DEADBAND

```python
DEADBAND = 1.5  # percent
```

The motor is stopped and the integral resets whenever the fader is within `DEADBAND`% of the target. This prevents the motor from hunting back and forth due to friction and mechanical backlash.

- **Too small**: Fader buzzes at rest trying to correct tiny errors.
- **Too large**: Fader stops noticeably before the target position.

For most motorized faders, 1–2% works well.

---

## INTEGRAL_MAX (Anti-Windup)

```python
INTEGRAL_MAX = 50.0
```

Clamps the integral term to prevent runaway accumulation when the fader is held back (e.g., user gripping it). Without this limit, the integral builds up while blocked, then dumps into the motor violently when released.

If you see a sudden surge when releasing the fader after holding it, reduce this value.

---

## Step-by-Step Tuning Procedure

This manual procedure is more reliable than Ziegler-Nichols for motorized faders, because faders respond fast and mechanically — Z-N tends to produce overly aggressive integral values.

### Step 1: Disable Ki and Kd

```python
KP = 0.3
KI = 0.0
KD = 0.0
```

Start conservative.

### Step 2: Tune Kp

Run `host.py` and send a setpoint: `0 0` then `100 100`. Watch how the fader moves.

- Increase Kp in steps of 0.1 until the fader moves briskly to the target.
- If it starts oscillating (bouncing back and forth), reduce Kp by 20%.
- The Kp where oscillation just starts is your "critical gain". Use 60–70% of that value.

Typical working range: **0.4 – 1.2**

### Step 3: Add Kd

With Kp set, add a small Kd to reduce overshoot:

```python
KD = 0.01
```

Increase in steps of 0.01 until overshoot is gone. Stop before the fader starts vibrating.

Typical working range: **0.01 – 0.05**

### Step 4: Add Ki (only if needed)

If the fader consistently stops short of the target (steady-state error), add a small Ki:

```python
KI = 0.01
```

Increase slowly. If the fader starts oscillating again (slowly), reduce Ki.

Typical working range: **0.0 – 0.1**

### Step 5: Check DEADBAND

With PID tuned, verify the deadband feels right:
- Fader should hold position without buzzing.
- Fader should reach the exact target (within 1–2%) before stopping.

Adjust `DEADBAND` in 0.5% increments.

---

## Symptom / Fix Table

| Symptom | Likely Cause | Fix |
|---|---|-----|
| Fader moves sluggishly | Kp too low | Increase Kp by 0.1 |
| Fader oscillates around target | Kp too high | Reduce Kp by 20% |
| Fader overshoots then oscillates | Kd too low | Increase Kd by 0.01 |
| Fader vibrates rapidly at rest | Kd too high or ADC noise | Reduce Kd; ensure WiFi is disabled on Pico |
| Fader stops just short of target | Ki too low or DEADBAND too large | Increase Ki by 0.01 or reduce DEADBAND |
| Fader oscillates slowly (long period) | Ki too high | Reduce Ki by 0.01 |
| Fader surges after being released | Integral windup | Reduce INTEGRAL_MAX |
| Fader doesn't move at all | PWM_MIN too high or STBY low | Check wiring; reduce PWM_MIN |
| Fader moves in wrong direction | Motor wires swapped | Swap AO1/AO2 connections |

---

## Notes on the Alps RS60N11M9

- The fader has some mechanical friction and a small amount of backlash. This means a deadband of at least 1% is always needed.
- The motor responds quickly — Kd matters more than Ki for this fader.
- ADC noise: on a genuine Pico W the ADC is affected by the CYW43 WiFi radio, so the firmware disables WiFi at startup. On the RP2040+RTL8720 clone board this `network` call may silently no-op — if you see random position jitter, suspect supply noise or wiring before software.
- The `initFaders()` calibration sweep runs automatically on boot. If the fader hits a mechanical stop and stalls, the calibration still completes — the final ADC values will be accurate.

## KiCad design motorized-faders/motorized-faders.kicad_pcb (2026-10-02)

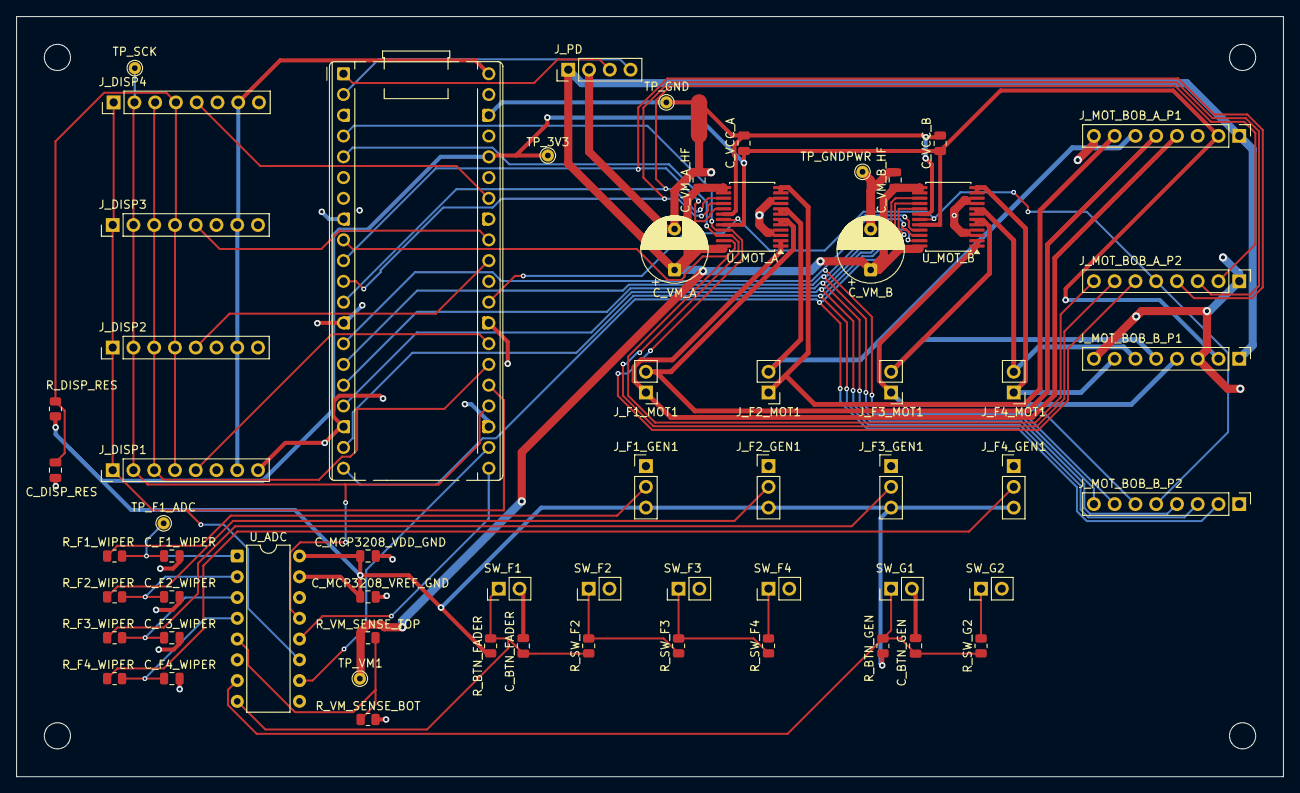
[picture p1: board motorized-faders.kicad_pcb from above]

Board: 2 copper layers, 155.0 x 93.0 mm, 62 parts (0 on the bottom side), 53 nets.

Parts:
A1: RaspberryPi_Pico; RaspberryPi_Pico_Common_THT
C_BTN_FADER: 100nF; C_0805_2012Metric
C_BTN_GEN: 100nF; C_0805_2012Metric
C_DISP_RES: 100nF; C_0805_2012Metric
C_F1_WIPER, C_F2_WIPER, C_F3_WIPER, C_F4_WIPER: 10nF; C_0805_2012Metric
C_MCP3208_VDD_GND, C_MCP3208_VREF_GND: 100nF; C_0805_2012Metric
C_VCC_A: 100nF ceramic; C_0805_2012Metric
C_VCC_B: 100nF ceramic; C_0805_2012Metric
C_VM_A: 100uF electrolytic; CP_Radial_D8.0mm_P5.00mm
C_VM_A_HF: 100nF ceramic; C_0805_2012Metric
C_VM_B: 100uF electrolytic; CP_Radial_D8.0mm_P5.00mm
C_VM_B_HF: 100nF ceramic; C_0805_2012Metric
J_DISP1, J_DISP2, J_DISP3, J_DISP4: Conn_01x08; PinHeader_1x08_P2.54mm_Vertical
J_F1_GEN1, J_F2_GEN1, J_F3_GEN1, J_F4_GEN1: Conn_01x03; PinHeader_1x03_P2.54mm_Vertical
J_F1_MOT1, J_F2_MOT1, J_F3_MOT1, J_F4_MOT1: Conn_01x02; PinHeader_1x02_P2.54mm_Vertical
J_MOT_BOB_A_P1, J_MOT_BOB_A_P2: Conn_01x08; PinHeader_1x08_P2.54mm_Vertical
J_MOT_BOB_B_P1, J_MOT_BOB_B_P2: Conn_01x08; PinHeader_1x08_P2.54mm_Vertical
J_PD: Conn_01x04; PinHeader_1x04_P2.54mm_Vertical
NT1: NetTie_2; NetTie-2_SMD_Pad2.0mm
R_BTN_FADER: 10kOhm; R_0805_2012Metric
R_BTN_GEN: 10kOhm; R_0805_2012Metric
R_DISP_RES: 10kOhm; R_0805_2012Metric
R_F1_WIPER, R_F2_WIPER, R_F3_WIPER, R_F4_WIPER: 10kOhm; R_0805_2012Metric
R_SW_F2: 2.2kOhm; R_0805_2012Metric
R_SW_F3: 4.7kOhm; R_0805_2012Metric
R_SW_F4: 10kOhm; R_0805_2012Metric
R_SW_G2: 4.7kOhm; R_0805_2012Metric
R_VM_SENSE_BOT: 3.3kOhm; R_0805_2012Metric
R_VM_SENSE_TOP: 10kOhm; R_0805_2012Metric
SW_F1, SW_F2, SW_F3, SW_F4: B3F-4050; PinHeader_1x02_P2.54mm_Vertical
SW_G1, SW_G2: B3F-4050; PinHeader_1x02_P2.54mm_Vertical
TP_3V3: TestPoint; TestPoint_THTPad_D1.5mm_Drill0.7mm
TP_F1_ADC: TestPoint; TestPoint_THTPad_D1.5mm_Drill0.7mm
TP_GND: TestPoint; TestPoint_THTPad_D1.5mm_Drill0.7mm
TP_GNDPWR: TestPoint; TestPoint_THTPad_D1.5mm_Drill0.7mm
TP_SCK: TestPoint; TestPoint_THTPad_D1.5mm_Drill0.7mm
TP_VM1: TestPoint; TestPoint_THTPad_D1.5mm_Drill0.7mm
U_ADC: MCP3208; DIP-16_W7.62mm
U_MOT_A: TB6612FNG; SSOP-24_5.3x8.2mm_P0.65mm
U_MOT_B: TB6612FNG; SSOP-24_5.3x8.2mm_P0.65mm

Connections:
+3V3: A1.36 (3V3), C_MCP3208_VDD_GND.1, C_MCP3208_VREF_GND.1, C_VCC_A.1, C_VCC_B.1, J_F1_GEN1.3, J_F2_GEN1.3, J_F3_GEN1.3, J_F4_GEN1.3, J_MOT_BOB_A_P1.2, J_MOT_BOB_B_P1.2, R_BTN_FADER.1, R_BTN_GEN.1, R_DISP_RES.1, TP_3V3.1 (1_1), U_ADC.15 (Vref), U_ADC.16 (Vdd), U_MOT_A.20 (VCC), U_MOT_B.20 (VCC)
+5V: A1.40 (VBUS), J_DISP1.7, J_DISP2.7, J_DISP3.7, J_DISP4.7
+9V: C_VM_A.1, C_VM_A_HF.1, C_VM_B.1, C_VM_B_HF.1, J_MOT_BOB_A_P1.1, J_MOT_BOB_B_P1.1, J_PD.1, R_VM_SENSE_TOP.1, TP_VM1.1 (1_1), U_MOT_A.13 (VM2), U_MOT_A.14 (VM3), U_MOT_A.24 (VM1), U_MOT_B.13 (VM2), U_MOT_B.14 (VM3), U_MOT_B.24 (VM1)
/A_AIN1: A1.4 (GPIO2), J_MOT_BOB_A_P2.6, U_MOT_A.21 (AIN1)
/A_AIN2: A1.5 (GPIO3), J_MOT_BOB_A_P2.7, U_MOT_A.22 (AIN2)
/A_BIN1: A1.10 (GPIO7), J_MOT_BOB_A_P2.4, U_MOT_A.17 (BIN1)
/A_BIN2: A1.11 (GPIO8), J_MOT_BOB_A_P2.3, U_MOT_A.16 (BIN2)
/A_PWMA: A1.9 (GPIO6), J_MOT_BOB_A_P2.8, U_MOT_A.23 (PWMA)
/A_PWMB: A1.12 (GPIO9), J_MOT_BOB_A_P2.2, U_MOT_A.15 (PWMB)
/BTN_FADER: C_BTN_FADER.1, R_BTN_FADER.2, R_SW_F2.1, SW_F1.1, U_ADC.8 (CH7)
/BTN_GEN: C_BTN_GEN.1, R_BTN_GEN.2, R_SW_G2.1, SW_G1.1, U_ADC.7 (CH6)
/B_AIN1: A1.14 (GPIO10), J_MOT_BOB_B_P2.6, U_MOT_B.21 (AIN1)
/B_AIN2: A1.15 (GPIO11), J_MOT_BOB_B_P2.7, U_MOT_B.22 (AIN2)
/B_BIN1: A1.17 (GPIO13), J_MOT_BOB_B_P2.4, U_MOT_B.17 (BIN1)
/B_BIN2: A1.19 (GPIO14), J_MOT_BOB_B_P2.3, U_MOT_B.16 (BIN2)
/B_PWMA: A1.16 (GPIO12), J_MOT_BOB_B_P2.8, U_MOT_B.23 (PWMA)
/B_PWMB: A1.20 (GPIO15), J_MOT_BOB_B_P2.2, U_MOT_B.15 (PWMB)
/DISP1_CS: A1.27 (GPIO21), J_DISP1.5
/DISP2_CS: A1.31 (GPIO26_ADC0), J_DISP2.5
/DISP3_CS: A1.32 (GPIO27_ADC1), J_DISP3.5
/DISP4_CS: A1.34 (GPIO28_ADC2), J_DISP4.5
/DISP_DC: A1.26 (GPIO20), J_DISP1.3, J_DISP2.3, J_DISP3.3, J_DISP4.3
/DISP_RES: C_DISP_RES.2, J_DISP1.4, J_DISP2.4, J_DISP3.4, J_DISP4.4, R_DISP_RES.2
/F1_ADC: C_F1_WIPER.1, R_F1_WIPER.2, TP_F1_ADC.1 (1_1), U_ADC.1 (CH0)
/F1_MOT_A: J_F1_MOT1.1, J_MOT_BOB_A_P1.4, U_MOT_A.1 (AO1), U_MOT_A.2 (AO1)
/F1_MOT_B: J_F1_MOT1.2, J_MOT_BOB_A_P1.5, U_MOT_A.5 (AO2), U_MOT_A.6 (AO2)
/F1_WIPER: J_F1_GEN1.2, R_F1_WIPER.1
/F2_ADC: C_F2_WIPER.1, R_F2_WIPER.2, U_ADC.2 (CH1)
/F2_MOT_A: J_F2_MOT1.1, J_MOT_BOB_A_P1.7, U_MOT_A.11 (BO1), U_MOT_A.12 (BO1)
/F2_MOT_B: J_F2_MOT1.2, J_MOT_BOB_A_P1.6, U_MOT_A.7 (BO2), U_MOT_A.8 (BO2)
/F2_WIPER: J_F2_GEN1.2, R_F2_WIPER.1
/F3_ADC: C_F3_WIPER.1, R_F3_WIPER.2, U_ADC.3 (CH2)
/F3_MOT_A: J_F3_MOT1.1, J_MOT_BOB_B_P1.4, U_MOT_B.1 (AO1), U_MOT_B.2 (AO1)
/F3_MOT_B: J_F3_MOT1.2, J_MOT_BOB_B_P1.5, U_MOT_B.5 (AO2), U_MOT_B.6 (AO2)
/F3_WIPER: J_F3_GEN1.2, R_F3_WIPER.1
/F4_ADC: C_F4_WIPER.1, R_F4_WIPER.2, U_ADC.4 (CH3)
/F4_MOT_A: J_F4_MOT1.1, J_MOT_BOB_B_P1.7, U_MOT_B.11 (BO1), U_MOT_B.12 (BO1)
/F4_MOT_B: J_F4_MOT1.2, J_MOT_BOB_B_P1.6, U_MOT_B.7 (BO2), U_MOT_B.8 (BO2)
/F4_WIPER: J_F4_GEN1.2, R_F4_WIPER.1
/I2C_SCL: A1.2 (GPIO1), J_PD.4
/I2C_SDA: A1.1 (GPIO0), J_PD.3
/MCP3208_CS: A1.22 (GPIO17), U_ADC.10 (~CS/SHDN)
/SPI_MISO: A1.21 (GPIO16), U_ADC.12 (Dout)
/SPI_MOSI: A1.25 (GPIO19), J_DISP1.1, J_DISP2.1, J_DISP3.1, J_DISP4.1, U_ADC.11 (Din)
/SPI_SCK: A1.24 (GPIO18), J_DISP1.2, J_DISP2.2, J_DISP3.2, J_DISP4.2, TP_SCK.1 (1_1), U_ADC.13 (CLK)
/STBY: A1.29 (GPIO22), J_MOT_BOB_A_P2.5, J_MOT_BOB_B_P2.5, U_MOT_A.19 (STBY), U_MOT_B.19 (STBY)
/VM_SENSE: R_VM_SENSE_BOT.1, R_VM_SENSE_TOP.2, U_ADC.5 (CH4)
GND: A1.3 (GND), A1.8 (GND), A1.13 (GND), A1.18 (GND), A1.23 (GND), A1.28 (GND), A1.38 (GND), C_BTN_FADER.2, C_BTN_GEN.2, C_DISP_RES.1, C_F1_WIPER.2, C_F2_WIPER.2, C_F3_WIPER.2, C_F4_WIPER.2, C_MCP3208_VDD_GND.2, C_MCP3208_VREF_GND.2, C_VCC_A.2, C_VCC_B.2, J_DISP1.8, J_DISP2.8, J_DISP3.8, J_DISP4.8, J_F1_GEN1.1, J_F2_GEN1.1, J_F3_GEN1.1, J_F4_GEN1.1, NT1.2, R_VM_SENSE_BOT.2, SW_F1.2, SW_F2.2, SW_F3.2, SW_F4.2, SW_G1.2, SW_G2.2, TP_GND.1 (1_1), U_ADC.9 (DGND), U_ADC.14 (AGND), U_MOT_A.18 (GND), U_MOT_B.18 (GND)
GNDPWR: C_VM_A.2, C_VM_A_HF.2, C_VM_B.2, C_VM_B_HF.2, J_MOT_BOB_A_P1.3, J_MOT_BOB_A_P1.8, J_MOT_BOB_A_P2.1, J_MOT_BOB_B_P1.3, J_MOT_BOB_B_P1.8, J_MOT_BOB_B_P2.1, J_PD.2, NT1.1, TP_GNDPWR.1 (1_1), U_MOT_A.3 (PGND1), U_MOT_A.4 (PGND1), U_MOT_A.9 (PGND2), U_MOT_A.10 (PGND2), U_MOT_B.3 (PGND1), U_MOT_B.4 (PGND1), U_MOT_B.9 (PGND2), U_MOT_B.10 (PGND2)
unnamed: R_SW_F2.2, R_SW_F3.1, SW_F2.1
unnamed: R_SW_F3.2, R_SW_F4.1, SW_F3.1
unnamed: R_SW_F4.2, SW_F4.1
unnamed: R_SW_G2.2, SW_G2.1

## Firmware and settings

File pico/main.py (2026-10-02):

"""
Motorized Fader Controller — MicroPython firmware for the 4-fader PCB.

Hardware per docs/pcb_design.md:
  Faders:   4x Alps RSA0N11M9 (100 mm, 10 kOhm), wipers -> MCP3208 CH0-CH3
  ADC:      MCP3208 12-bit 8-channel SPI, VREF ratiometric with fader supply
  Drivers:  2x TB6612FNG, faders 1-2 on driver A, faders 3-4 on driver B
  Displays: 4x SSD1306 128x64 SPI (Adafruit 938), shared SCK/MOSI/DC, own CS
  Buttons:  resistor ladders on MCP3208 CH6 (2 general) and CH7 (4 per-fader)
  Rail:     VM divider into MCP3208 CH4, checked at boot before enabling STBY
  Motor:    9 V from a USB-C PD trigger (PD has no 10 V PDO)

SPI0 is shared between the MCP3208 and all four displays. Safe because the
displays are write-only, so only the MCP3208 ever drives MISO.

Serial protocol (115200 baud, USB). All lines newline-terminated:

  Pico -> Host
    POS:f1,f2,f3,f4          position, 0-100%, one slot per fader
    RAW:r1,r2,r3,r4          raw ADC 0-65535, diagnostics, sent while engaged
    STATE:idx,IDLE|MOVING|SETTLING       idx is 1-based
    BTN:F1..F4|G1|G2         button press edge; the host assigns meaning
    MUTE:idx,0|1             mute state confirmation, idx is 1-based
    RAIL:ok,<volts> | RAIL:fail,<volts>  VM check result at boot
    CAL:start | CAL:done
    DBG:<text>

  Host -> Pico
    SET:f1,f2,f3,f4          setpoints, 0-100%; an empty slot means
                             "leave this fader unchanged"
    MUTE:idx,0|1             mute/unmute fader idx (1-based). Muting parks the
                             fader at the bottom and remembers where it was;
                             unmuting drives it back there.
    DISP:idx,line1,line2     display text for fader idx (1-based). Content is
                             whatever the active host plugin wants to show.

Buttons report presses only — the firmware assigns them no function. The host
decides what a press means, which is what makes a future layer-switch button
a host-side config change rather than a firmware change.
"""

import sys
import select
from machine import Pin, SPI
from utime import ticks_ms, ticks_diff

from lib.buttons import ButtonLadder, FADER_LADDER, GENERAL_LADDER
from lib.fader_screen import FaderScreen
from lib.mcp3208 import MCP3208
from lib.ssd1306_spi import SSD1306_SPI

# ---------------------------------------------------------------------------
# PID tuning constants — adjust these to tune your faders
# ---------------------------------------------------------------------------
KP = 3.5          # Proportional gain — main driving force
KI = 1.5          # Integral gain — corrects steady-state error
KD = 0.05         # Derivative gain — damping, reduces overshoot

DEADBAND = 0.2    # % — motor stops when within this distance of target
DEADBAND_EXIT = 0.5  # % — must exceed this to leave hold state (hysteresis)

# Anti-windup: integral is clamped to this range
INTEGRAL_MAX = 100.0

# Minimum motor output (%) when actively moving — below this the motor
# crawls near stall. Floor non-zero PID output to this to keep short
# moves brisk. Set to 0 to disable.
# Raised from 30.0 for the 9 V motor rail: USB PD has no 10 V PDO, so the
# motors run 10% under their rated voltage (docs/pcb_design.md).
MIN_MOVE_PCT = 35.0

# Calibration sweep power, likewise raised for 9 V (was 60 at 10 V).
CAL_MOTOR_POWER = 70

# Calibration sweeps run until the wiper stops moving, not for a fixed time:
# the RSA0N11M9 has 100 mm of travel (the prototype's RS60N11M9 had 60 mm), so
# any duration long enough to be safe is mostly wasted, and one that is too
# short silently calibrates against a mid-travel point instead of a hard stop.
# A sweep ends when consecutive reads differ by less than CAL_STALL_COUNTS for
# CAL_STALL_READS in a row, meaning the carriage is against its end stop.
CAL_STALL_COUNTS = 120      # of 65535 — ~0.2% of travel
CAL_STALL_READS = 4
CAL_SWEEP_STEP_MS = 30
CAL_SWEEP_TIMEOUT_MS = 4000  # backstop: a disconnected motor must not hang boot

# State machine: motor only runs on demand. After SET:, drive to target,
# hold for SETTLE_MS within deadband, then release. While idle, report
# position only when it changes by REPORT_DELTA (user moved the fader).
SETTLE_MS = 1000
REPORT_DELTA = 0.2

# Muting parks the fader at the bottom. Movement below this point is not read
# as the user choosing a new unmute target — it is the fader sitting where mute
# put it. calibrate() trims 1% of span as margin, so a commanded 0% settles a
# little above true zero and the zone has to clear that.
MUTE_PARK_ZONE_PCT = 3.0

# ---------------------------------------------------------------------------
# Motor / hardware constants
# ---------------------------------------------------------------------------
PWM_FREQ = 20000  # Hz — 20kHz is above hearing range, no motor whine
# Minimum PWM duty below which motor stalls rather than moving slowly.
# Below this threshold the output is treated as zero (coast).
PWM_MIN = 10000
PWM_MAX = 65535

# ---------------------------------------------------------------------------
# Pin map — validated in docs/pcb_design.md against two hardware constraints:
# SPI0 on legal pins, and the four PWM outputs on four distinct slices.
# ---------------------------------------------------------------------------
PIN_STBY = 22          # shared by both TB6612FNG

# (in1, in2, pwm) per fader. PWM pins are GP6/9/12/15 -> slices 3/4/6/7.
MOTOR_PINS = (
    (2, 3, 6),      # fader 1 — driver A channel A
    (7, 8, 9),      # fader 2 — driver A channel B
    (10, 11, 12),   # fader 3 — driver B channel A
    (13, 14, 15),   # fader 4 — driver B channel B
)

PIN_SPI_SCK = 18
PIN_SPI_MOSI = 19
PIN_SPI_MISO = 16
PIN_MCP_CS = 17
PIN_DISP_DC = 20
DISPLAY_CS_PINS = (21, 26, 27, 28)

# ~1 MHz: safe for the MCP3208 at 3.3 V, trivial for the SSD1306. A full
# 128x64 frame is 1 KB, ~8 ms — which is why screens redraw on change only.
SPI_BAUDRATE = 1_000_000

# MCP3208 channel assignment
ADC_CH_FADER = (0, 1, 2, 3)
ADC_CH_VM_RAIL = 4
ADC_CH_GENERAL_BTN = 6
ADC_CH_FADER_BTN = 7

MCP_FULL_SCALE = 4095
ADC_VREF = 3.3

# ---------------------------------------------------------------------------
# VM rail check — a divider into CH4 catches the HUSB238's silent 5 V
# fallback, which otherwise presents as a mechanical fault (docs/pcb_design.md)
# ---------------------------------------------------------------------------
VM_DIVIDER_TOP = 10000.0     # ohms, VM -> CH4
VM_DIVIDER_BOTTOM = 3300.0   # ohms, CH4 -> GND
VM_EXPECTED_V = 9.0
VM_TOLERANCE_V = 1.2        # accepts a sagging 9 V, rejects 5 V and 12 V

# ---------------------------------------------------------------------------
# Hardware configuration — set False for any fader not connected
# ---------------------------------------------------------------------------
FADER_ENABLED = (True, True, True, True)
NUM_FADERS = len(FADER_ENABLED)

# ---------------------------------------------------------------------------
# Serial / timing
# ---------------------------------------------------------------------------
POS_INTERVAL_MS = 50   # send position every 50ms (~20Hz)
MAX_DT_S = 0.1         # cap dt to prevent derivative spike on first PID call
BUTTON_POLL_MS = 15    # buttons are slow; no need to read them every loop
DISPLAY_POLL_MS = 100  # rate limit for redraws, which still only run on change

# The SSD1306's RC reset needs ~5 ms to release before the first command.
DISPLAY_RESET_MS = 10


class MotorDriver:
    def __init__(self, in1, in2, pwm_pin, stby):
        from machine import PWM
        self.in1 = Pin(in1, Pin.OUT)
        self.in2 = Pin(in2, Pin.OUT)
        self.pwm = PWM(Pin(pwm_pin))
        self.pwm.freq(PWM_FREQ)
        # STBY is shared by all four channels, so it is owned by main() and
        # passed in already configured rather than re-created per motor.
        self.stby = stby

    def drive(self, power):
        """
        Drive motor at given power (-100.0 to +100.0).
        Positive = forward (fader up), negative = reverse (fader down).
        """
        duty = int(abs(power) / 100.0 * PWM_MAX)
        if 0 < duty < PWM_MIN:
            # Below stall threshold — boost to PWM_MIN so motor actually moves
            duty = PWM_MIN
        duty = min(duty, PWM_MAX)

        if power > 0:
            self.in1.value(1)
            self.in2.value(0)
        elif power < 0:
            self.in1.value(0)
            self.in2.value(1)
        else:
            self.in1.value(0)
            self.in2.value(0)  # coast

        self.pwm.duty_u16(duty)

    def stop(self):
        self.drive(0)


class FaderPID:
    def __init__(self, read_raw, motor):
        # Hardware access is isolated to this callable, so the ADC can be
        # swapped (internal ADC, MCP3208, a test stub) without touching the
        # control loop. Must return 0-65535.
        self._read = read_raw
        self.motor = motor

        # Calibrated ADC range (set by calibrate())
        self.adc_min = 0
        self.adc_max = 65535
        # True when the wiper reads high at the bottom of travel; set by
        # calibrate() from the observed sweep endpoints.
        self.inverted = False

        # PID state
        self.setpoint = 50.0  # will be overwritten after calibration
        self.integral = 0.0
        self.last_error = 0.0
        self.last_time = ticks_ms()
        # Hysteresis: once inside deadband, stay holding until error grows
        # past DEADBAND_EXIT. Prevents buzz from ADC flicker across edge.
        self.in_deadband = False

        # State machine: IDLE (motor off), MOVING (PID driving), SETTLING
        # (PID holding, counting down to release).
        self.state = "IDLE"
        self.settle_start = 0
        self.last_reported_pos = 0.0
        # Tracks last state we emitted on serial so main loop can dedupe.
        self._last_emitted_state = "IDLE"

        # Mute: the fader parks at the bottom and remembers where it was.
        # Unmuting drives it back. If the user moves a muted fader by hand,
        # that new position becomes the restore target, so pressing mute
        # again re-mutes from wherever they left it.
        self.muted = False
        self.unmute_position = 50.0

    def _raw_adc(self):
        """Average 16 samples to reduce noise (kills sub-% jitter)."""
        return sum(self._read() for _ in range(16)) // 16

    def read_raw(self):
        """Return raw ADC value (0-65535), uncalibrated."""
        return self._raw_adc()

    def read_position(self):
        """Return fader position as 0.0-100.0%, 0 = bottom of travel."""
        raw = self._raw_adc()
        raw = max(self.adc_min, min(self.adc_max, raw))
        span = self.adc_max - self.adc_min
        if span <= 0:
            # Calibration failed (collapsed range) — report 0 rather than
            # dividing by zero and killing the control loop.
            return 0.0
        pct = (raw - self.adc_min) / span * 100.0
        return 100.0 - pct if self.inverted else pct

    def calibrate(self, motor_power=CAL_MOTOR_POWER, settle_ms=400):
        """
        Auto-calibrate ADC range by driving fader to both mechanical limits.

        Wiper orientation is detected rather than assumed: whichever limit
        reads lower becomes adc_min, and self.inverted records whether the
        ADC counts down as the fader travels up.
        """
        # Drive to one mechanical limit, then the other. Which limit reads
        # higher on the ADC depends on how the wiper is wired, so don't
        # assume: record what each end actually reads and sort afterwards.
        #
        # The sweep ends when the wiper stops moving, which is the actual
        # condition we care about (carriage against the end stop). Driving for
        # a fixed number of steps instead would calibrate against wherever the
        # fader happened to reach, and that error propagates into every
        # position report afterwards.
        def _sweep(power):
            self.motor.drive(power)
            _delay(settle_ms)
            end = self._raw_adc()
            still = 0
            elapsed = settle_ms
            while still < CAL_STALL_READS and elapsed < CAL_SWEEP_TIMEOUT_MS:
                self.motor.drive(power)
                _delay(CAL_SWEEP_STEP_MS)
                elapsed += CAL_SWEEP_STEP_MS
                reading = self._raw_adc()
                if abs(reading - end) < CAL_STALL_COUNTS:
                    still += 1
                else:
                    still = 0
                end = reading
            self.motor.stop()
            _delay(100)
            if elapsed >= CAL_SWEEP_TIMEOUT_MS:
                # Motor unplugged, jammed, or the rail sagged — the endpoint is
                # not trustworthy. Say so rather than calibrating against it
                # silently.
                _emit("DBG:calibration sweep timed out, endpoint may be wrong")
            return end

        end_fwd = _sweep(motor_power)
        end_rev = _sweep(-motor_power)

        lower = min(end_fwd, end_rev)
        upper = max(end_fwd, end_rev)

        # Wiper polarity: if driving forward lands on the LOW ADC end, the
        # ADC counts down as the fader travels up, so position must be
        # flipped to keep 0% = bottom.
        self.inverted = end_fwd < end_rev

        # Add small margin to avoid clipping at extremes
        margin = int((upper - lower) * 0.01)
        self.adc_min = lower + margin
        self.adc_max = upper - margin

        # Boot in IDLE — fader free, no torque until host sends SET:
        self.setpoint = self.read_position()
        self.last_time = ticks_ms()
        self.state = "IDLE"
        self.motor.stop()
        self.last_reported_pos = self.setpoint
        self.unmute_position = self.setpoint

    def update(self):
        """
        Run one state-machine iteration. Returns current position (0-100%).
        IDLE: motor off, no PID. MOVING: PID drives to setpoint. SETTLING:
        PID still holds, releases motor after SETTLE_MS of stillness.
        """
        now = ticks_ms()
        dt = min(ticks_diff(now, self.last_time) / 1000.0, MAX_DT_S)
        self.last_time = now

        position = self.read_position()

        if self.state == "IDLE":
            # A muted fader the user has dragged somewhere: treat that as the
            # new restore target, so pressing mute again re-mutes from where
            # they left it. Nothing drives the motor in IDLE, so any movement
            # here is the user's hand.
            #
            # Exclude the park zone at the bottom. Muting leaves the fader
            # sitting there, and without this guard that parked position would
            # immediately overwrite the position we are supposed to restore.
            if (
                self.muted
                and position > MUTE_PARK_ZONE_PCT
                and abs(position - self.unmute_position) >= DEADBAND_EXIT
            ):
                self.unmute_position = position
            return position

        error = self.setpoint - position

        if self.state == "MOVING" and abs(error) < DEADBAND:
            self.state = "SETTLING"
            self.settle_start = now

        if self.state == "SETTLING":
            if abs(error) > DEADBAND_EXIT:
                self.state = "MOVING"
                self.integral = 0.0
                self.last_error = 0.0
            elif ticks_diff(now, self.settle_start) >= SETTLE_MS:
                self.motor.stop()
                self.integral = 0.0
                self.last_error = 0.0
                self.state = "IDLE"
                self.last_reported_pos = position
                return position
            else:
                # In deadband, waiting out settle timer — motor off, no PID.
                self.motor.stop()
                return position

        # PID (MOVING only)
        if dt > 0:
            self.integral += error * dt
            self.integral = max(-INTEGRAL_MAX, min(INTEGRAL_MAX, self.integral))
            derivative = (error - self.last_error) / dt
        else:
            derivative = 0.0

        self.last_error = error
        output = KP * error + KI * self.integral + KD * derivative
        output = max(-100.0, min(100.0, output))

        # Floor non-zero output so short moves don't crawl near stall
        if 0 < abs(output) < MIN_MOVE_PCT:
            output = MIN_MOVE_PCT if output > 0 else -MIN_MOVE_PCT

        self.motor.drive(output)
        return position

    def state_changed(self):
        """Return new state if it changed since last call, else None."""
        if self.state != self._last_emitted_state:
            self._last_emitted_state = self.state
            return self.state
        return None

    def engage(self, setpoint):
        """Set new target and arm the motor (state -> MOVING)."""
        self.setpoint = max(0.0, min(100.0, setpoint))
        self.integral = 0.0
        self.last_error = 0.0
        self.last_time = ticks_ms()
        self.in_deadband = False
        self.state = "MOVING"

    def set_mute(self, muted):
        """
        Mute: park at the bottom, remembering the current position.
        Unmute: drive back to the remembered position.

        Idempotent — re-muting an already-muted fader re-parks it, which is
        what the user wants after dragging a muted fader by hand.
        """
        if muted:
            # Capture the position to come back to. Prefer the live reading
            # over self.setpoint: the user may have moved the fader by hand
            # since the last SET:. Re-muting an already-muted fader the user
            # has dragged up must keep the target update()'s IDLE branch
            # recorded, so only read the fader when it is outside the park
            # zone — inside it, the stored target is the better answer.
            live = self.read_position()
            if live > MUTE_PARK_ZONE_PCT:
                self.unmute_position = live
            self.muted = True
            self.engage(0.0)
        else:
            self.muted = False
            self.engage(self.unmute_position)


def _delay(ms):
    """Blocking delay in milliseconds."""
    start = ticks_ms()
    while ticks_diff(ticks_ms(), start) < ms:
        pass


def _emit(line):
    sys.stdout.write(line + "\n")


def read_vm_rail(adc):
    """Return the VM rail voltage measured through the CH4 divider."""
    counts = sum(adc.read(ADC_CH_VM_RAIL) for _ in range(8)) // 8
    at_adc = counts / MCP_FULL_SCALE * ADC_VREF
    ratio = VM_DIVIDER_BOTTOM / (VM_DIVIDER_TOP + VM_DIVIDER_BOTTOM)
    return at_adc / ratio


def _parse_index(text):
    """Parse a 1-based fader index from the protocol into a 0-based one."""
    idx = int(text) - 1
    if not 0 <= idx < NUM_FADERS:
        raise ValueError("fader index out of range")
    return idx


def _handle_command(line, faders, screens):
    line = line.strip()
    if not line:
        return
    # Ignore everything that is not an input command — notably our own output
    # lines (CAL:, POS:, STATE:, ...), which can arrive back on stdin as a USB
    # CDC loopback and would otherwise be parsed as commands.
    try:
        if line.startswith("SET:"):
            _handle_set(line[4:], faders)
        elif line.startswith("MUTE:"):
            _handle_mute(line[5:], faders, screens)
        elif line.startswith("DISP:"):
            _handle_disp(line[5:], screens)
    except (ValueError, IndexError) as e:
        _emit("DBG:parse err {}".format(e))


def _handle_set(payload, faders):
    parts = payload.split(",")
    # An empty slot means "leave this fader alone" — the host only fills
    # slots something actually asked to move. Engaging every slot on every
    # SET: would re-command a fader the user is currently holding, or drive
    # it back to a stale setpoint.
    for idx, raw in enumerate(parts[:NUM_FADERS]):
        fader = faders[idx]
        if fader is None or not raw.strip():
            continue
        fader.engage(float(raw))


def _handle_mute(payload, faders, screens):
    parts = payload.split(",")
    if len(parts) < 2:
        raise ValueError("MUTE needs idx,state")
    idx = _parse_index(parts[0])
    fader = faders[idx]
    if fader is None:
        return
    muted = parts[1].strip() not in ("0", "", "false", "False")
    fader.set_mute(muted)
    if screens[idx] is not None:
        screens[idx].set_muted(muted)
    # Confirm, so the host tracks the state the firmware actually holds
    # rather than assuming its command landed.
    _emit("MUTE:{},{}".format(idx + 1, 1 if muted else 0))


def _handle_disp(payload, screens):
    # Only split off the index: the text itself may contain commas, and the
    # second comma separates the two lines.
    parts = payload.split(",", 2)
    idx = _parse_index(parts[0])
    if screens[idx] is None:
        return
    line1 = parts[1] if len(parts) > 1 else ""
    line2 = parts[2] if len(parts) > 2 else ""
    screens[idx].set_lines(line1, line2)


def _build_screens(spi):
    """Bring up the four displays. A missing display must not kill the rig."""
    dc = Pin(PIN_DISP_DC, Pin.OUT)
    # The shared RC reset on DISP_RES needs to release before the first
    # command reaches any controller.
    _delay(DISPLAY_RESET_MS)

    screens = []
    for idx in range(NUM_FADERS):
        if not FADER_ENABLED[idx]:
            screens.append(None)
            continue
        try:
            cs = Pin(DISPLAY_CS_PINS[idx], Pin.OUT)
            screens.append(FaderScreen(SSD1306_SPI(spi, dc, cs)))
        except Exception as e:
            # Displays are cosmetic; faders must still work without them.
            _emit("DBG:display {} init failed: {}".format(idx + 1, e))
            screens.append(None)
    return screens
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

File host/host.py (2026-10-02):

#!/usr/bin/env python3
"""
Motorized Fader Controller — PC host interface
Connects to Pico W over USB serial, displays fader positions,
and lets you send setpoints.

Usage:
    python host.py [/dev/ttyACM0]

Dependencies:
    pip install pyserial

Setpoint input:
    Type up to NUM_FADERS numbers separated by spaces or commas, e.g.:
        50 75 20 90 -> all four faders
        50 75       -> faders 1 and 2 only; 3 and 4 unchanged
        50          -> fader 1 only
        , , 30      -> fader 3 only (empty slots are skipped)
"""

import sys
import threading
import time
import serial
import serial.tools.list_ports

# Raspberry Pi Pico W USB VID (MicroPython USB serial)
PICO_VID = 0x2E8A
BAUD = 115200

# The 4-fader PCB reports four slots; the 2-fader breadboard reports two and
# the extra slots simply stay at 0.
NUM_FADERS = 4

state = {
    "positions": [0.0] * NUM_FADERS,
    "muted": [False] * NUM_FADERS,
    "status": "connecting",  # "connecting", "calibrating", "running", "error"
    "rail": None,            # None until the Pico reports RAIL:
}
state_lock = threading.Lock()


def find_pico_port():
    for port in serial.tools.list_ports.comports():
        if port.vid == PICO_VID:
            return port.device
    return None


def connect(port=None):
    if port is None:
        port = find_pico_port()
    if port is None:
        port = input(
            "Pico not found automatically. Enter serial port (e.g. /dev/ttyACM0): "
        ).strip()
    print(f"Connecting to {port} at {BAUD} baud...")
    ser = serial.Serial(port, BAUD, timeout=0.1)
    ser.reset_input_buffer()
    return ser


def parse_line(line):
    if line.startswith("POS:"):
        parts = line[4:].split(",")
        with state_lock:
            for idx, raw in enumerate(parts[:NUM_FADERS]):
                try:
                    state["positions"][idx] = float(raw)
                except ValueError:
                    continue
            state["status"] = "running"
    elif line.startswith("MUTE:"):
        parts = line[5:].split(",", 1)
        if len(parts) == 2:
            try:
                idx = int(parts[0]) - 1
            except ValueError:
                return
            if 0 <= idx < NUM_FADERS:
                with state_lock:
                    state["muted"][idx] = parts[1].strip() == "1"
    elif line.startswith("RAIL:"):
        parts = line[5:].split(",", 1)
        volts = parts[1].strip() if len(parts) > 1 else "?"
        with state_lock:
            state["rail"] = (parts[0].strip() == "ok", volts)
    elif line.startswith("BTN:"):
        # Buttons are handled by `faders.run`, not this bring-up tool. Print
        # them so the ladder can be verified by pressing each one.
        print(f"\r  [button] {line[4:].strip()}" + " " * 40)
    elif line.startswith("CAL:"):
        with state_lock:
            state["status"] = "calibrating" if "start" in line else "running"


def reader_thread(ser, stop_event):
    buf = ""
    while not stop_event.is_set():
        try:
            data = ser.read(64)
            if not data:
                continue
            buf += data.decode("ascii", errors="ignore")
            while "\n" in buf:
                line, buf = buf.split("\n", 1)
                parse_line(line.strip())
        except serial.SerialException:
            with state_lock:
                state["status"] = "error"
            break
        except Exception:
            time.sleep(0.05)


def make_bar(pct, width=20):
    filled = max(0, min(width, int(pct / 100.0 * width)))
    return "#" * filled + "-" * (width - filled)


def send_setpoint(ser, values):
    """`values` is a list of NUM_FADERS floats or None (leave unchanged)."""
    slots = ["" if v is None else f"{v:.1f}" for v in values]
    cmd = "SET:" + ",".join(slots) + "\n"
    try:
        ser.write(cmd.encode("ascii"))
    except serial.SerialException:
        print("\n[error] Failed to send — serial connection lost.")


def parse_input(text):
    """
    Parse user input into a list of NUM_FADERS setpoints, where None means
    "leave this fader unchanged".

    Accepts: '50 75 20 90', '50,75', '50', ', , 30' (fader 3 only).
    Returns the list, or None if nothing valid was given.
    """
    # Split on commas first so empty slots survive, then on whitespace.
    if "," in text:
        fields = [f.strip() for f in text.split(",")]
    else:
        fields = text.split()
    if not fields:
        return None

    values = [None] * NUM_FADERS
    errors = []
    got_one = False
    for idx, field in enumerate(fields[:NUM_FADERS]):
        if not field:
            continue
        try:
            value = float(field)
        except ValueError:
            errors.append(f"F{idx + 1}='{field}' is not a number")
            continue
        if not 0 <= value <= 100:
            errors.append(f"F{idx + 1}={value} out of range (0-100)")
            continue
        values[idx] = value
        got_one = True

    if errors:
        print("\n[warn] " + ", ".join(errors))
    return values if got_one else None


def display_loop(stop_event):
    """
    Runs in a daemon thread, overwrites the current line with fader status.
    The main thread's blocking input() call will interrupt this naturally.
    """
    while not stop_event.is_set():
        with state_lock:
            positions = list(state["positions"])
            muted = list(state["muted"])
            status = state["status"]
            rail = state["rail"]

        if status == "calibrating":
            status_str = "[calibrating...]"
        elif status == "error":
            status_str = "[serial error]"
        elif status == "connecting":
            status_str = "[waiting for data...]"
        elif rail is not None and not rail[0]:
            status_str = f"[RAIL FAIL {rail[1]}V — motors disabled]"
        else:
            status_str = ""

        cells = []
        for idx, pos in enumerate(positions):
            flag = "M" if muted[idx] else " "
            cells.append(f"F{idx + 1}{flag}{pos:5.1f}% [{make_bar(pos, 10)}]")
        sys.stdout.write("\r  " + "  ".join(cells) + f"  {status_str}   ")
        sys.stdout.flush()
        time.sleep(0.1)
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

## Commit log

2026-06-21 work without touch pin
2026-09-13 fix: detect wiper orientation during calibration
    [main.py]
2026-09-28 sparse SET: slots so idle faders stay put
2026-09-28 add 4-fader PCB design doc
2026-09-28 pcb: 2+4 button split, SPI pin constraints, measured footprints
2026-09-28 pcb: USB-C PD power, VM rail check, I2C mux for future use
2026-09-28 pcb: correct HUSB238 part no, price and availability
2026-09-28 pcb: pin map, mechanical, reverse-polarity, USB panel mounting
2026-09-28 pcb: drop stale 10uF rail bulk, no 5V rail on board
2026-09-28 pcb: Adafruit 938 8-pin display, VIN from 5V rail
2026-09-28 pcb: SPI net naming table and MCP3208 pinout
2026-09-28 pcb: specify DISP_RES RC circuit and timing
2026-09-28 pcb: TB6612FNG pinout matches KiCad symbol names
2026-09-29 add KiCad schematic for 4-fader PCB
    [display.kicad_sch, fader.kicad_sch, motorized-faders.kicad_pcb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]
2026-09-29 pcb: drop 470uF rail cap, obsolete since USB-C PD
2026-09-29 kicad: assign all footprints
    [display.kicad_sch, fader.kicad_sch, motorized-faders.kicad_sch]
2026-09-29 pcb: header wiring not soldered, add mounting holes, place components
    [display.kicad_sch, fader.kicad_sch, motorized-faders.kicad_pcb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]
2026-09-29 pcb: route signal and power traces, grounds pending
    [motorized-faders.kicad_pcb]
2026-09-29 pcb: grounds, first DRC errors fixed
    [motorized-faders.kicad_pcb, motorized-faders.kicad_sch]
2026-10-01 pcb: add TB6612 breakout headers, finish routing and grounds
    [motorized-faders.kicad_pcb, motorized-faders.kicad_sch]
2026-10-02 pcb: configure gerber plot output, ignore fab files
    [motorized-faders.kicad_pcb]
2026-10-02 firmware: 4-fader ADC, displays, buttons, mute
2026-10-24 firmware: stall guard, short brake, breakaway ramp, live TUNE: gains
2026-10-24 host: add PID autotune script
2026-10-24 firmware: skip display redraws mid-move, retune PID gains
2026-10-24 firmware: report button release edges as BTNUP:
2026-10-24 host: G2 + fader button swaps between A/B positions
2026-10-24 display: show restore position while muted, A/B slot badge
2026-10-24 cad: parametric case for 4 faders, Adafruit 326 displays, B3F buttons
2026-10-25 cad: bottom-loaded button boxes with slide-in retaining bars
2026-10-25 cad: heat-set inserts for PCB (M3) and PD board (M2) standoffs
2026-10-25 cad: printable button caps with mute and A/B labels
2026-10-30 host: Pico hot-replug reconnect, flake with NixOS user service and plugin config
2026-10-31 host: switchable plugin layers, Discord voice plugin with paging and slider-scale volume, G1 layer switch on release
2026-10-31 home_assistant: switch/input_boolean faders, follow=false for bogus reports, bad entries no longer crash the host
2026-11-06 filter_param: PipeWire filter-chain controls on faders, saved across restarts
2026-11-06 core: commanded fader level holds within settle band, no drift on layer switch
2026-11-06 fader_screen: G2 held marks other A/B slot's position on the bar
2026-11-08 media: current player volume, mute, play/pause, next, previous on Linux and Windows
